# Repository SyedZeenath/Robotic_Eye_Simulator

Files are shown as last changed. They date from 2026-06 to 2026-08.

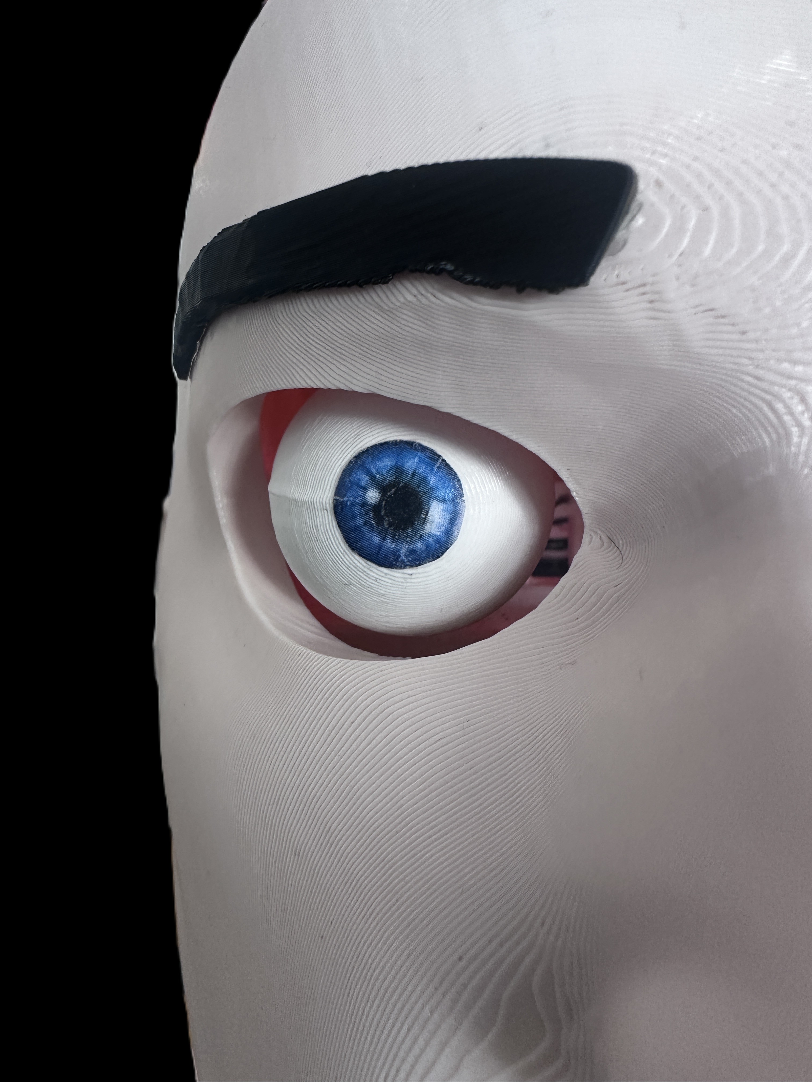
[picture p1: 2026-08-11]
Images/Evaluations/Eye_angles/h4.JPG

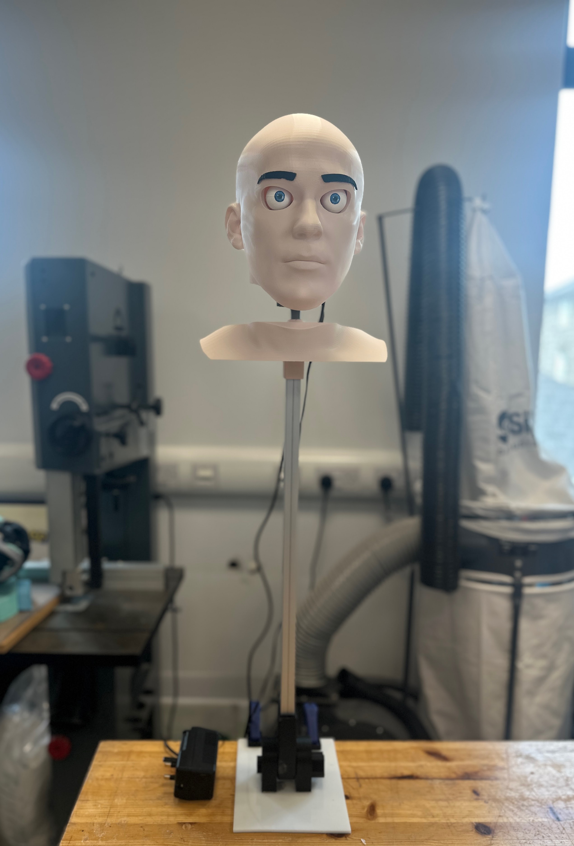
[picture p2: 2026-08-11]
Images/full_setup.JPG

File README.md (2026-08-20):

# Robotic Eye Movement Simulator for the Dix-Hallpike Test

## Overview

This dissertation project implements a robotic eye movement system for simulating the eye responses associated with the Dix-Hallpike test for BPPV research and training. The system combines Arduino-based hardware control, IMU head tracking, servo-driven eye movement and a Unity-based digital interface.

The platform provides real-time eye movement simulation, a guided clinical test workflow, patient data management, calibration tools and performance evaluation. The physical robotic head and the Unity model communicate through a USB serial connection.

## System Architecture

The system is divided into four main parts:

1. **Physical robotic platform** - A head and eye mechanism driven by six servo motors.
2. **Arduino controller** - Reads head movement from the MPU6050, controls the eye motors through the PCA9685 and communicates with Unity.
3. **Unity frontend** - Displays the digital head and eye model, manages the test workflow and provides monitoring and patient-management functions.
4. **Evaluation tools and data** - Calibration tools and recorded CSV data are used to evaluate positional synchronisation, latency and IMU behaviour.

### Data Flow

```text
Physical head movement / IMU
            ↓
        Arduino
            ↓
     USB Serial 115200
            ↓
 ArduinoSerialReader
            ↓
 RealisticEyeController
            ↓
  Unity head and eye model
            ↓
        User display
```

The Unity interface can also send commands back to the Arduino to start right-side, left-side or neutral sequences.

## Project Structure

### `/EyeController/`

Arduino firmware for motor control, IMU tracking, BPPV sequence control, calibration and evaluation.

- **`EyeController.ino`** - Main Arduino sketch containing:
  - MPU6050 head tracking using the Digital Motion Processor (DMP)
  - PCA9685 servo control
  - Six-channel eye movement control
  - Mirror-effect handling between the two eyes
  - Clinical test state machine
  - Physical-to-digital calibration lookup tables
  - Serial communication with Unity
  - Evaluation routines for positional synchronisation and IMU jitter/noise
  - `SKIP_IMU_TEST` option for bench testing without the IMU

### `/Frontend/`

Unity project containing the digital twin, user interface, clinical workflow and evaluation tools.

#### `Assets/Scripts/`

- **`ArduinoSerialReader.cs`** - Reads and parses serial data from the Arduino.
- **`RealisticEyeController.cs`** - Applies eye angles to the digital model and handles VOR compensation and head velocity tracking.
- **`SimulationUI.cs`** - Controls the main simulation interface.
- **`InstructionManager.cs`** - Controls the eight-step Dix-Hallpike instruction sequence.
- **`InstructionStep.cs`** - Defines an individual instruction step.
- **`DiagnosisFeedbackController.cs`** - Handles assessment feedback shown during the test.
- **`LatencyMonitor.cs`** - Records communication and timing information.
- **`SyncDebugOverlay.cs`** - Displays synchronisation and debugging information.
- **`EnvLoader.cs`** - Loads runtime environment and configuration settings from the `env` file in `Assets/StreamingAssets/` (see API Configuration below).
- **`RecordingIndicator.cs`** - Displays recording status.
- **`TTS_Script.cs`** / **`STT_Script.cs`** - Text-to-speech and speech-to-text functions.
- **`MicrophoneRecorder.cs`** - Handles audio recording.
- **`WavUtility.cs`** - Provides WAV file handling utilities.

#### `Assets/Scripts/PatientModel/`

- **`PatientManager.cs`** - Maintains the current patient data.
- **`Patient.cs`** - Defines the patient data model.
- **`PatientList.cs`** - Manages the patient collection.
- **`PatientItemUI.cs`** - Displays an individual patient entry.
- **`PatientListUI.cs`** - Controls the patient list interface.

#### Other Unity folders

- **`Assets/Scenes/`**
  - `MainScene.unity` - Main simulation scene.
  - `SampleScene.unity` - Development and testing scene.
- **`Assets/Prefab/`** - Reusable head and eye components.
- **`Assets/Resources/`** - Patient JSON data, textures, materials and other runtime resources.
  - `patients.json` - Patient data used by the application.
- **`Assets/StreamingAssets/`** - Additional runtime data and configuration, including the `env` configuration file (see API Configuration below). This folder is copied automatically into every build output, which is what lets the `env` file travel with a shared build without any manual copy step.
- **`Assets/Eye/`** - Eye model assets, materials and prefabs.
- **`Assets/HeadModel/`** - Head model assets and geometry.
- **`Packages/`** - Unity package configuration and dependencies.
- **`ProjectSettings/`** - Unity project and build settings.

Generated folders such as `Logs/` and `Temp/` are not required for the source project and can be omitted from version control.

### `/Models/`

CAD models for the physical robotic platform:

- **`Body_Of_Robotic_Bppv_Head.stl`** - Main head structure.
- **`Rod_Holder_Torso.stl`** - Torso mounting component.
- **`Eye_Mechanism/`** - Eye mechanism components.
- **`Head/`** - Head assembly components.
- **`Neck/`** - Neck joint components.
- **`Base_Hinge_Joint/`** - Base hinge components.

### `/Helpers/`

- **`photo_angle_measurer.html`** - Browser-based tool used to measure physical eye angles during calibration.

### `/Images/`

Evaluation and calibration material:

- **`Evaluations/Eye_angles/`** - Recorded eye-angle measurements.
- **`Evaluations/Head_angles/`** - Recorded head-angle measurements.
- Calibration screenshots and supporting images.

### `/Builds/`

Prebuilt standalone application and evaluation data generated during testing:

- **A prebuilt `.exe` and its accompanying `_Data` folder** - the standalone Windows build of the application. If no changes need to be made to the project, this can be run directly without opening or importing the project in Unity. Run the `Robotic_Eye_Simulator.exe` from inside this folder as-is; the `_Data` folder (which contains the bundled `StreamingAssets/env` file among other runtime data) must stay alongside the `Robotic_Eye_Simulator.exe`, since a Unity build is not a single portable file. Copying or sharing the `Robotic_Eye_Simulator.exe` on its own, without its `_Data` folder, will not run.
  (Only for the dissertation scope; `/Builds/` may be removed later.)
- **`latency_results.csv`** - Serial communication latency measurements.
- **`sync_results.csv`** - Motor synchronisation measurements.
- **`transfer_latency_results.csv`** - Data transfer latency measurements.

## Hardware Requirements

The tested system uses:

- **Arduino UNO R3** - Main microcontroller.
- **MPU6050** - Six-axis accelerometer/gyroscope for head tracking.
- **PCA9685** - 16-channel PWM driver for servo control.
- **Six servo motors**:
  - Right eye: horizontal, vertical and torsional movement.
  - Left eye: horizontal, vertical and torsional movement.
- **Motor power supply** - Separate suitable supply for the servo motors.
- **USB connection** - Arduino-to-PC serial communication.

### PCA9685 Channel Mapping

| Eye | Horizontal | Vertical | Torsion |
| ----- | ---: | ---: | ---: |
| Right | CH0 | CH1 | CH2 |
| Left  | CH4 | CH5 | CH6 |

Channels CH3 and CH7-15 are unused by the current implementation.

## Software Requirements

- **Arduino IDE** 1.8.x or later.
- **I2Cdev** library.
- **MPU6050** library with DMP support.
- **Adafruit PWM Servo Driver** library.
- **Unity** 2022.x or later; an LTS release is recommended.
- **TextMesh Pro** for the Unity interface.
- **Windows audio system** for the TTS/STT functions.
- **Visual Studio** for C# development.

## Setup

### 1. API Configuration

The Unity application uses Google Cloud Text-to-Speech (TTS) and Speech-to-Text (STT) services. The required API keys must be stored in a plain-text configuration file named **`env`** (no leading dot) placed at:

```text
Assets/StreamingAssets/env
```

The leading dot was dropped deliberately: Unity's asset importer does not reliably include files whose names begin with a dot when copying `StreamingAssets` into a build, so a dotfile placed there can silently fail to ship with the built application. Naming the file `env` instead avoids this and ensures it is bundled correctly every time the project is built.

Create the file by copying the format from `Frontend/.env.example`:

```env
GOOGLE_TTS_API_KEY=your-google-cloud-tts-api-key-here
GOOGLE_STT_API_KEY=your-google-cloud-stt-api-key-here
```

For the dissertation version, the personal API keys required to run the application are already included in the `Frontend/.env.example` file for demonstration and evaluation purposes. These keys will be removed after the dissertation evaluation. These keys can be used now for testing the application.

To create new API keys, create or select a project in the Google Cloud Console, enable the **Cloud Text-to-Speech API** and **Cloud Speech-to-Text API**, then create an API key under **APIs & Services → Credentials**. Add the generated keys to the corresponding entries in `env`.

`EnvLoader.cs` reads this file via `Application.streamingAssetsPath`, which resolves correctly both in the Unity Editor and in a standalone build, so no manual copying is required as long as the file lives in `Assets/StreamingAssets/env` before building.

The `env` file should not be committed to version control.

### 2. Arduino

1. Install the Arduino IDE.
2. Install the required I2Cdev, MPU6050 and Adafruit PWM Servo Driver libraries.
3. Connect the MPU6050 and PCA9685 to the Arduino I2C interface.
4. Connect the six servo motors to the PCA9685 channels listed above.
5. Open `EyeController/EyeController.ino`.
6. Select the correct board and COM port.
7. Upload the firmware.

For bench testing without the IMU, set:

```cpp
SKIP_IMU_TEST = true
```

The serial interface uses **115200 baud**.

### 3. Unity

1. Install Unity 2022.x or a compatible LTS release.
2. Open the `Frontend/` directory through Unity Hub.
3. Allow Unity to complete the initial asset import.
4. Open `Assets/Scenes/MainScene.unity`.
5. Check the `ArduinoSerialReader` component and confirm the COM port.
6. Confirm the baud rate is set to 115200.
7. Check the patient data file if patient information needs to be changed.
8. Press **Play** to test the application in the Unity Editor.

TTS/STT functions require the appropriate Windows audio and microphone permissions.

> **Note:** If you only need to run the application as-is, with no code, scene, or asset changes, you do not need to open Unity at all. See `/Builds/` above for the prebuilt `.exe`.

## Calibration

The physical eye mechanism requires calibration before comparing physical and digital eye positions.

### Photo Angle Measurement

Open:

```text
Helpers/photo_angle_measurer.html
```

The tool is used to measure physical eye angles and relate them to the corresponding digital motor commands. The resulting values are used by the calibration lookup tables in the Arduino firmware.

### Evaluation Data Collection

The firmware contains a separate evaluation section for:

- Positional synchronisation testing.
- IMU jitter and noise measurements.
- Calibration data collection.

The Unity application also provides `LatencyMonitor` and `SyncDebugOverlay` components for monitoring system behaviour during testing.

Evaluation results are stored in the `/Builds/` directory.

## Communication Protocol

Communication between Arduino and Unity uses text-based USB serial communication at 115200 baud.

### Unity → Arduino

```text
R                  Right-side BPPV sequence
L                  Left-side BPPV sequence
N                  Neutral position
C:<h>,<v>,<t>      Calibration command
```

### Arduino → Unity

The Arduino sends status and eye-angle information in a text format containing the current phase and horizontal, vertical and torsional angles.

The exact message format is implemented in `EyeController.ino` and parsed by `ArduinoSerialReader.cs`.

## Running the System

### Quick Run (no changes needed)

If the application does not need any modification, the prebuilt standalone build in `/Builds/` can be run directly. The application opens at the home section, which is the starting point for patient selection, simulation and evaluation:

1. Open the `/Builds/` folder.
2. Run the `Robotic_Eye_Simulator.exe` found there directly, no Unity installation required on the target machine.
3. Keep the `Robotic_Eye_Simulator.exe` and its accompanying `_Data` folder together in the same location; do not copy or share the `Robotic_Eye_Simulator.exe` on its own.
4. Connect the Arduino and confirm the correct COM port as described in the Troubleshooting section if the serial connection is not detected automatically.

### Bench Test

For motor-only testing:

1. Set `SKIP_IMU_TEST = true`.
2. Upload the Arduino firmware.
3. Open the Serial Monitor at 115200 baud.
4. Send `R`, `L` or `N`.
5. Check that the motors respond correctly.

### Full System Test

1. Connect the Arduino and physical eye mechanism.
2. Connect the MPU6050.
3. Start the Unity application (either the Editor or the prebuilt `Robotic_Eye_Simulator.exe`).
4. Confirm that the serial connection is active.
5. Select a patient if required.
6. Start the Dix-Hallpike test workflow.
7. Follow the on-screen instructions.
8. Monitor the physical and digital eye movements.
9. Use the debugging and latency tools when collecting evaluation data.

### Clinical Test Workflow

The Unity interface provides an eight-step test sequence covering the right and left sides. The instruction system guides the user through the sequence, while the digital head and eye model display the corresponding movement.

Patient information and test outcomes can be stored through the patient-management system.

## Evaluation and Monitoring

The project includes tools for evaluating the physical and digital system.

### Latency

`LatencyMonitor.cs` records communication timing during system operation. Recorded latency results are stored as CSV data for later analysis.

### Positional Synchronisation

The physical eye positions are compared with their corresponding digital positions using calibration and synchronisation data.

### IMU Stability

The Arduino evaluation section can be used to collect IMU jitter and noise data while the head is held in controlled positions.

### Debugging

`SyncDebugOverlay.cs` can display:

- Current test phase.
- Motor angles.
- Head rotation.
- IMU information.
- Timing information.

These tools are intended for development and evaluation and can be disabled during normal operation.

## Key Features

### Robotic Eye and Head System

- Independent three-axis movement for each eye.
- Six servo-driven eye axes.
- MPU6050-based head tracking.
- PCA9685 PWM motor control.
- Calibration lookup tables for physical-to-digital angle mapping.
- Mirror-effect handling between the two eyes.

### Unity Digital Twin

- Real-time 3D head and eye visualisation.
- Serial-driven eye movement.
- Head rotation visualisation.
- VOR compensation.
- Guided Dix-Hallpike workflow.

### Patient and Test Management

- JSON-based patient data.
- Patient selection and management.
- Test result and diagnosis feedback.
- Eight-step test instruction system.
- TTS/STT functions.
- Microphone recording support.

### Evaluation

- Serial latency monitoring.
- Positional synchronisation testing.
- IMU jitter/noise testing.
- Calibration tools.
- CSV export of evaluation data.

## Technical Details

### Arduino Firmware

The firmware is organised into the following sections:

1. **Declarations** - Configuration values, calibration data, state variables and IMU data.
2. **BPPV Core** - Motor control, calibration, state-machine operation, head tracking and serial commands.
3. **Evaluation** - Positional synchronisation and IMU data collection.
4. **Main Loop** - Continuous IMU processing, motor updates, serial handling and telemetry.

The BPPV sequence is implemented as a state machine covering the required test phases.

### Eye Motor Control

The PCA9685 controls six servo channels. Physical motor positions are mapped to target angles using calibration data. Smoothing is applied to reduce visible movement caused by variations in serial updates.

The left and right eye movements use mirrored horizontal and torsional values where required by the mechanical arrangement.

### IMU and Head Tracking

The MPU6050 provides accelerometer and gyroscope measurements. Its Digital Motion Processor is used for quaternion-based motion processing. Head pitch, roll and yaw are used by the Unity system for head movement and VOR-related calculations.

### Data Persistence

- **Patient data:** JSON format in `Assets/Resources/patients.json`.
- **Configuration/secrets:** `env` file in `Assets/StreamingAssets/`.
- **Evaluation results:** CSV files in `Frontend/`.
- **Calibration:** Stored in the Arduino firmware calibration data.

## Building the Unity Application

1. Open **File → Build Settings**.
2. Add `Assets/Scenes/MainScene.unity`.
3. Select Windows as the target platform used for this project.
4. Configure the required resolution and presentation settings.
5. Build the standalone application.
6. Confirm that `Assets/StreamingAssets/env` exists before building, so the required API keys are bundled into the output automatically.
7. On the target system, connect the Arduino and confirm the serial port configuration.

The application was developed and tested on Windows 10/11.

> **Sharing a build:** always share the full build output folder (the `Robotic_Eye_Simulator.exe` together with its `_Data` folder), never the `Robotic_Eye_Simulator.exe` file alone. The `_Data` folder contains `StreamingAssets/env` and other runtime data the application needs to run.

## Troubleshooting

### Serial connection is not detected

- Check that the Arduino is connected.
- Confirm the COM port in `ArduinoSerialReader`.
- Confirm that both sides use 115200 baud.
- Close other applications using the same serial port.
- Restart the Arduino and Unity application if necessary.

### Motors do not move

- Check the PCA9685 I2C connection.
- Check the PCA9685 address.
- Check the separate motor power supply.
- Check the servo connections.
- Test the `R`, `L` and `N` commands through the Serial Monitor.

### IMU does not initialise

- Check the MPU6050 SDA/SCL connections.
- Confirm that the required MPU6050 and I2Cdev libraries are installed.
- Check the I2C address.
- Use `SKIP_IMU_TEST = true` for motor-only testing.

### Eye movement is unstable

- Check the motor power supply.
- Check USB and I2C connections.
- Check the smoothing setting in `RealisticEyeController`.
- Use the synchronisation overlay to identify whether the problem originates from the physical or digital side.

### TTS/STT does not work

- Confirm the `env` file exists at `Assets/StreamingAssets/env` (or, for a built application, inside the `_Data/StreamingAssets/` folder shipped alongside the `.exe`) and that the Google Cloud TTS and STT API keys are correctly set inside it, as described in the API Configuration section.
- If running a shared build, confirm the `Robotic_Eye_Simulator.exe` was not copied or shared without its `_Data` folder.
- Check Windows microphone permissions.
- Confirm that the correct audio input/output devices are selected.
- Check Unity audio settings.
- If nothing appears on screen, check `Player.log` (typically under `%USERPROFILE%\AppData\LocalLow\<CompanyName>\<ProductName>\Player.log` on Windows) for the specific error, since a standalone build has no visible console by default.

## Testing Strategy

The project uses several levels of testing:

- **Component testing** - Individual motor, IMU and serial functions.
- **Integration testing** - Arduino-to-Unity communication and digital eye response.
- **System testing** - End-to-end operation of the physical and digital systems.
- **Evaluation testing** - Latency, positional synchronisation and IMU stability measurements.

The detailed experimental methodology and results are documented in the dissertation.

## Development and Extension

The main extension points are:

1. **Additional BPPV sequences** - Extend the Arduino state machine.
2. **Additional patient fields** - Update `Patient.cs` and the JSON data structure.
3. **Additional instructions** - Extend the instruction definitions in `InstructionManager`.
4. **Motor calibration** - Update the calibration data for the relevant PCA9685 channels.

## Limitations and Notes

- The system was developed and tested primarily on Windows 10/11.
- The physical platform and digital model require calibration before positional comparisons are made.
- Servo response and mechanical accuracy depend on the physical hardware and power supply.
- TTS/STT functionality depends on the host computer's audio configuration.
- The system is intended as a research and training platform; clinical diagnostic validity has not been established by this project.
- Hardware limits should be maintained to prevent the eye mechanism from being driven beyond its safe mechanical range.
- Sharing the application requires sharing the full build output folder; the `Robotic_Eye_Simulator.exe` alone will not run and will not carry the bundled `env` configuration.

## Future Work

Possible extensions include:

- Supporting additional BPPV canal variants.
- Increasing the available torsional mechanical range.
- Evaluating trainee learning outcomes.
- Developing an alternative interface for training and demonstration.

## Project Status

- **Project:** Dissertation research project.
- **Platform:** Arduino + Unity.
- **Primary target:** Windows 10/11.
- **Physical system:** Robotic head with six servo-driven eye axes.
- **Main application:** BPPV/Dix-Hallpike simulation and research evaluation.

## Acknowledgments

I thank Dr. JahanZeb Gul and Dr. Gerard Boyle for their supervision and feedback throughout this project. I'm also grateful to the clinical nursing staff and the design engineering team at St.James's Hospital, Dublin, whose consultation shaped the assessment protocol and instruction language used in this platform.

Particular thanks go to Arslan Akhtar, a Year 3 Innovation & Design student at Maynooth University, who worked as part of the St.James's design team during his internship there and contributed to the mechanical design of the head and support structures.

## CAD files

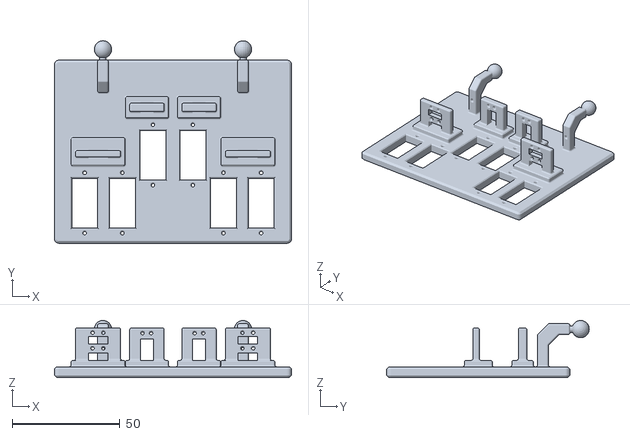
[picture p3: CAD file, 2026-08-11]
Models/Eye_Mechanism/Full_base.STL
110.0 x 94.0 x 26.5

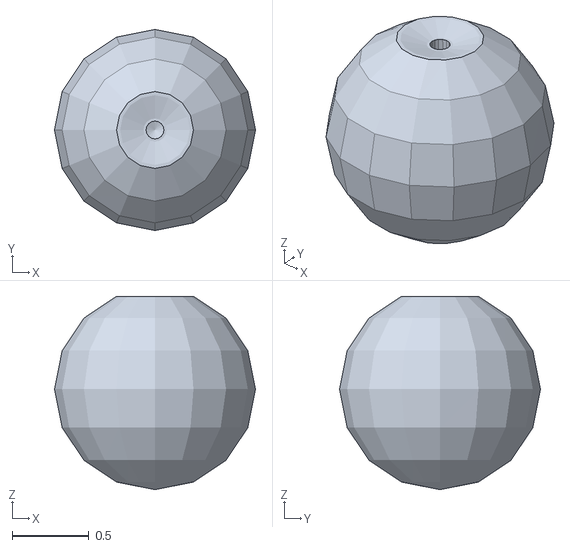
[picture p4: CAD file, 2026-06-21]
Frontend/Assets/Eye/Model/iris.obj
1.31 x 1.31 x 1.26

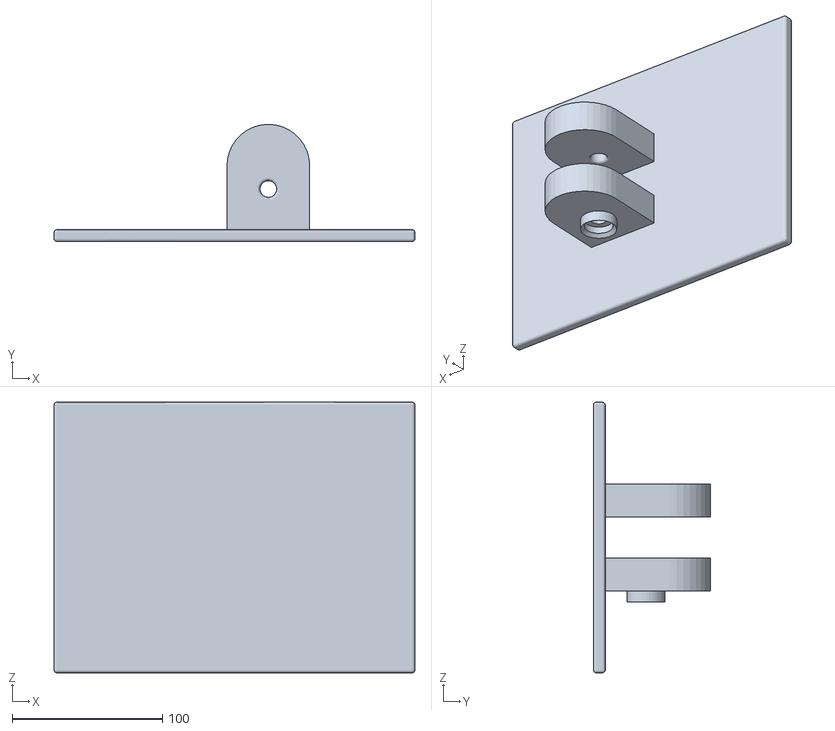
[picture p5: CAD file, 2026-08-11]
Models/Base_Hinge_Joint/base.STL
240.0 x 78.0 x 180.0

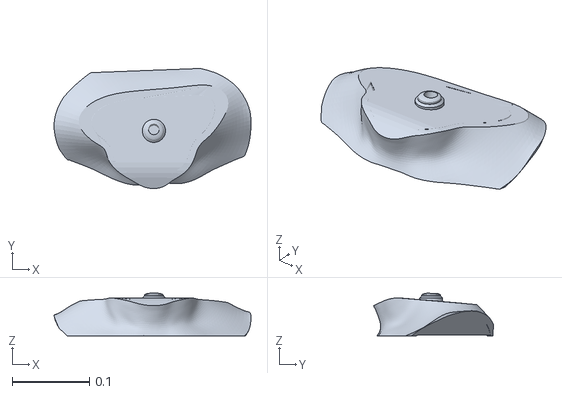
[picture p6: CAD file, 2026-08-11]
Models/Body Of Robotic Bppv Head.stl
0.256 x 0.156 x 0.0555

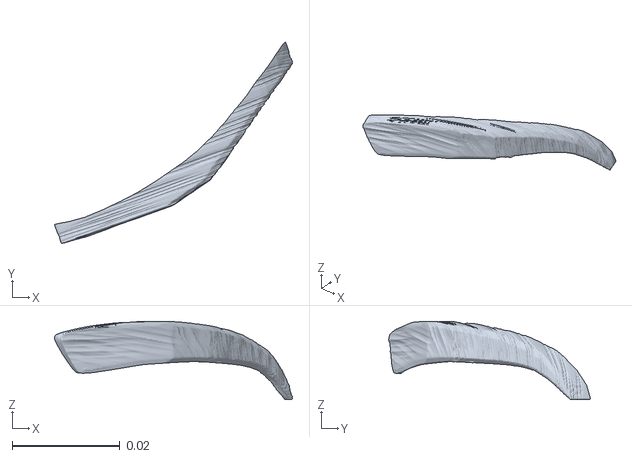
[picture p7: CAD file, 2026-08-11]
Models/Head/EyeBrow Left.stl
0.0441 x 0.0374 x 0.0145

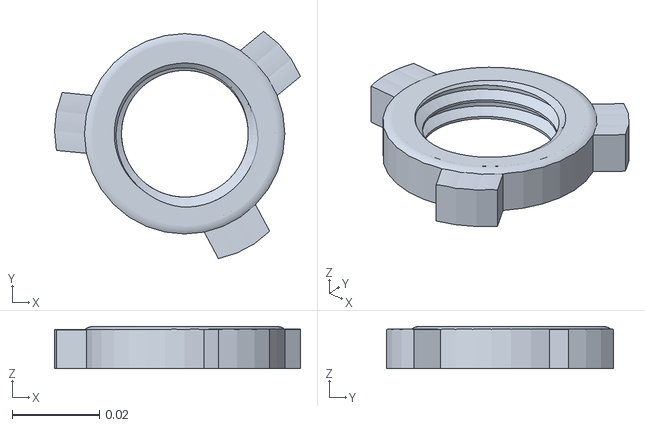
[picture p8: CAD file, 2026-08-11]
Models/Neck/Tightner Ball Joint .stl
0.0565 x 0.0522 x 0.00976

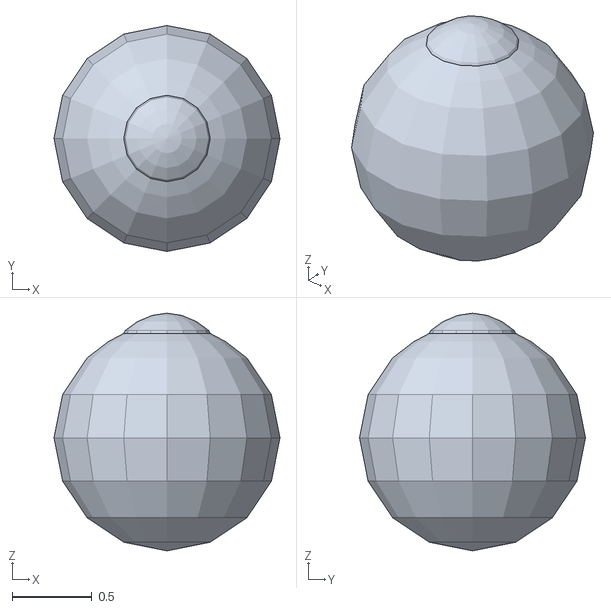
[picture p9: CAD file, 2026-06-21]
Frontend/Assets/Eye/Model/sclera.obj
1.42 x 1.42 x 1.49

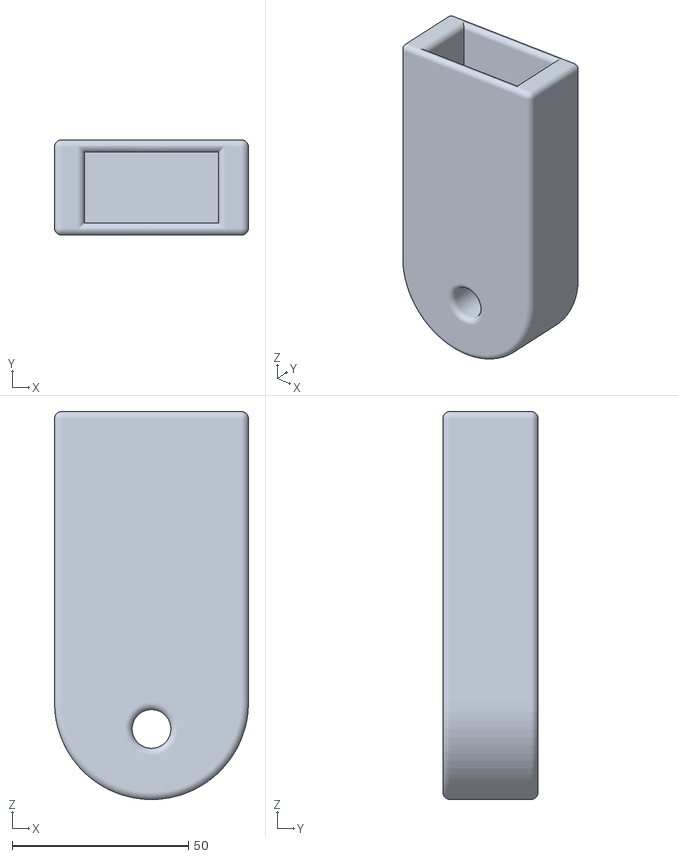
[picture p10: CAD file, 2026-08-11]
Models/Base_Hinge_Joint/RodAttachment.STL
55.0 x 27.0 x 110.0

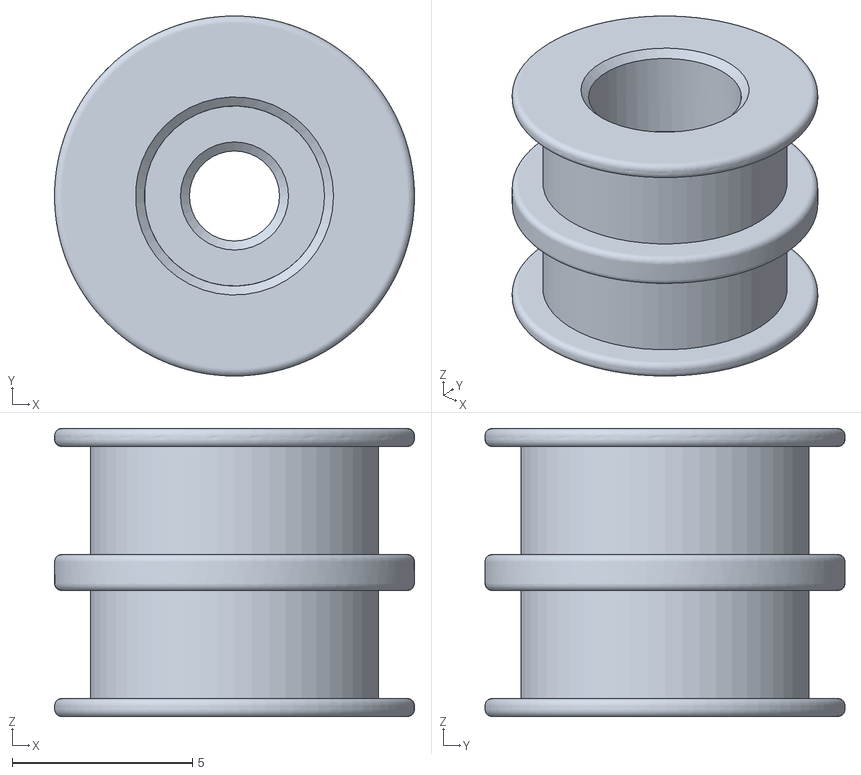
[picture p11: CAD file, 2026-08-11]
Models/Eye_Mechanism/motor_dual_spool.STL
10.0 x 10.00 x 8.00

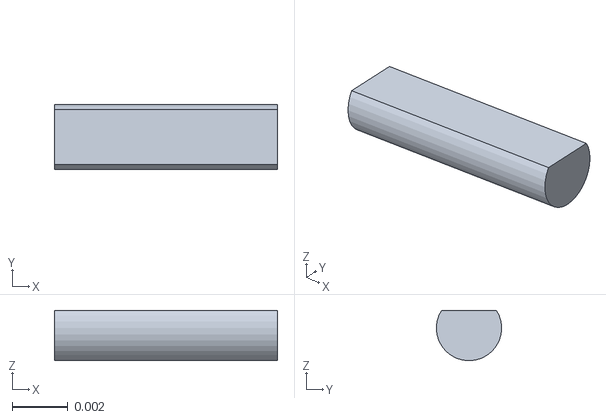
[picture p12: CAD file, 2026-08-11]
Models/Head/POwer Controller Pins.stl
0.008 x 0.00235 x 0.00181

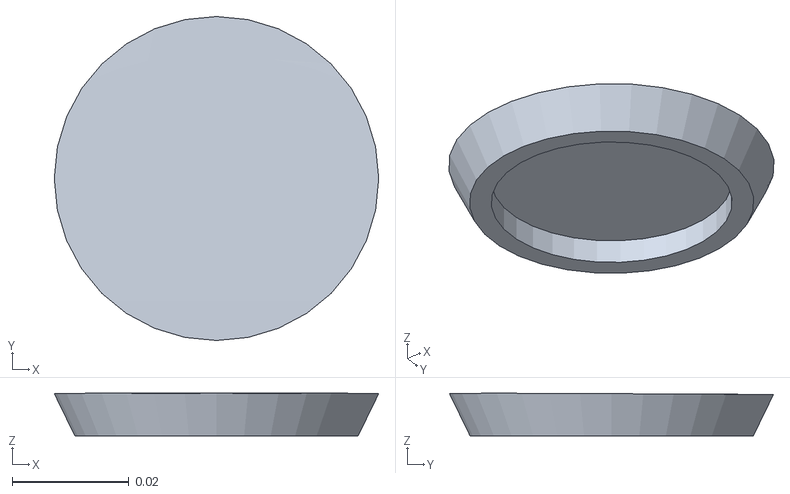
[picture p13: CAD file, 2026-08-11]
Models/Neck/Head Joint Holder .stl
0.0556 x 0.0555 x 0.00732

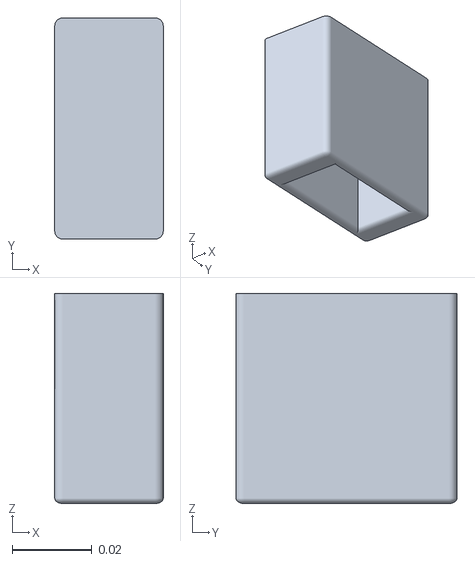
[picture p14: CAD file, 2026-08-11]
Models/Rod Holder Torso.stl
0.0273 x 0.0556 x 0.0528

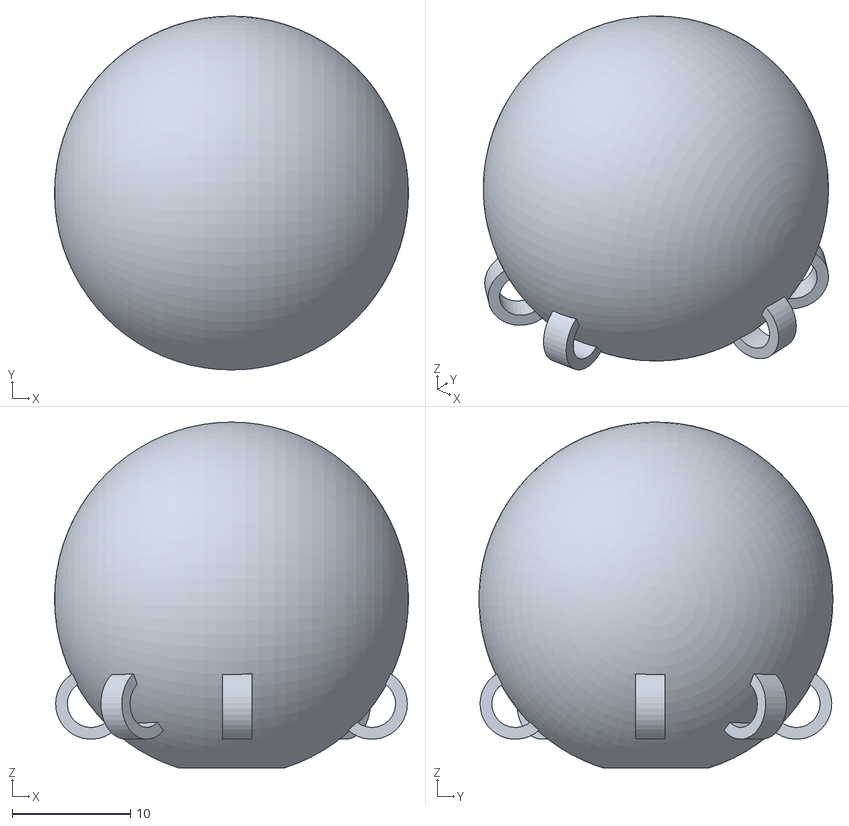
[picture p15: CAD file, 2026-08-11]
Models/Eye_Mechanism/Eye_Sphere_loop.STL
30.0 x 30.0 x 29.3

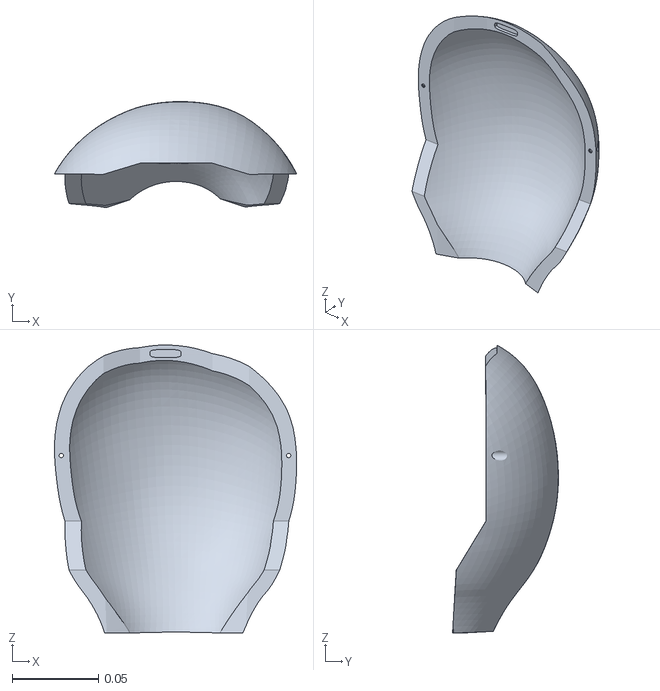
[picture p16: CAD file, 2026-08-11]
Models/Head/Backdoor.stl
0.14 x 0.0613 x 0.167

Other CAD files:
Models/Head/Power Controller Holder Side wall .stl
Models/Neck/Ball Joint.stl
Models/Head/Head .stl
Models/Base_Hinge_Joint/Screw_Head.STL
Models/Neck/Screw Ball Joint.stl

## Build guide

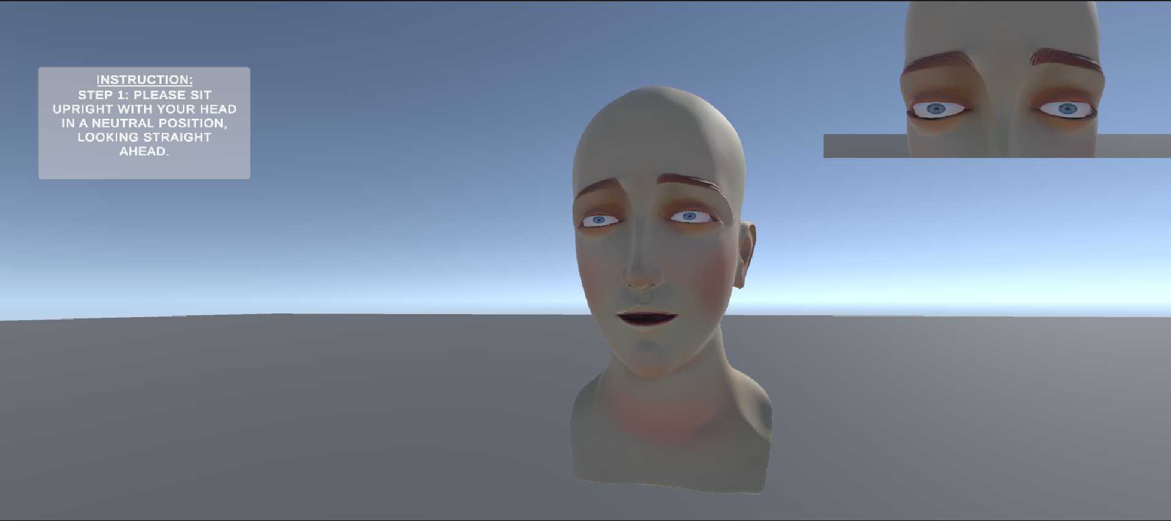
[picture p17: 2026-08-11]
Images/step2-Unity.png

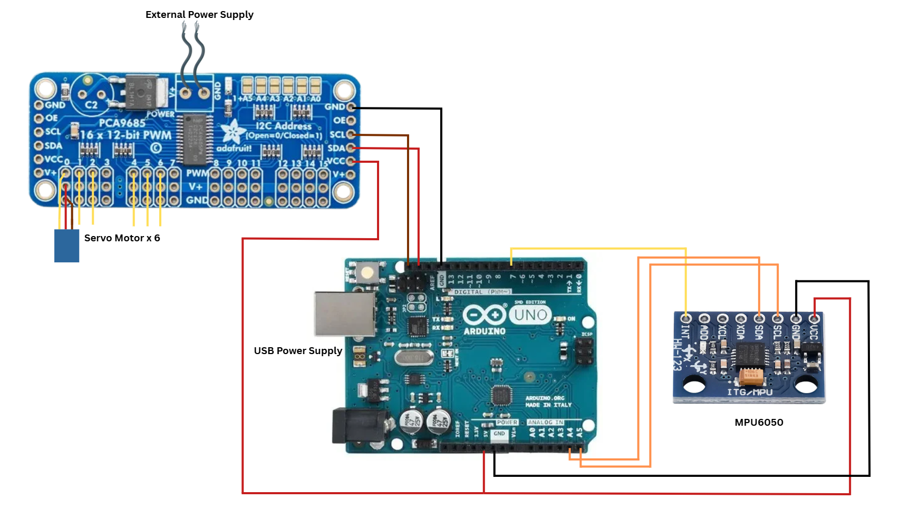
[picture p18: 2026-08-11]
Images/wiringDiagram.png

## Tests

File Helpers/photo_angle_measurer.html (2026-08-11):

# Photo Angle Measurer

The zoom helps you see the pixel, but a mouse click is still limited to the screen's resolution, not the photo's, so it can't reliably land on the exact same image pixel twice. To actually get pixel-repeatable points: every canvas below now shows the live cursor position in real image pixels, click a point roughly where you want it, then use the arrow keys to nudge the last point 1px at a time (hold Shift for 5px) while watching the X/Y readout, or just type the exact X,Y pixel values into the boxes and hit "Add point at typed pixel" to place it with no mouse imprecision at all. Note down the X/Y numbers for a point you like, and you can type those exact same numbers back in next time.

## Mode 1: Torsion (in-plane rotation angle)

Use this for torsion only. Click three points in order:

1. Pivot (red) - center of the pupil/iris (torsion rotates around this point, it does not move)
2. Fixed reference (blue) - an identifiable mark on the STATIC housing (paint dot, screw, seam) that does NOT move with the eye. Defines your 0deg direction.
3. Moving marker (green) - a specific identifiable spot in the iris texture pattern, placed near the EDGE of the iris, well away from the pivot. The farther from the pivot, the more precise the reading.

zoom

cursor: (-, -) X: Y: Add point at typed pixel Arrow keys nudge the last placed point (Shift = 5px).

Load a photo, then click: 1) pivot, 2) fixed reference, 3) moving marker.

No neutral set yet. Measure your 0deg commanded photo first, then click "Set as neutral".

Set as neutral (this = 0deg) Record this measurement Reset points (same photo) Download recorded CSV

# | label | raw angle (deg) | torsion vs neutral (deg)

## Mode 2: Vertical / Horizontal (displacement angle)

Vertical and horizontal eye movement is NOT an in-plane rotation as seen from a straight-on camera - it shows up as the pupil sliding up/down or left/right in the frame. This mode measures that displacement and converts it to degrees using the eye's own radius, so it needs a fixed camera position (tripod) between the neutral shot and every test shot - if the camera moves, the numbers are meaningless.

### Step A: set the neutral position (eye at 0,0,0)

Load the neutral photo. First click 3 to 8 points spread around the IRIS edge (the blue/dark ring, not the white sclera edge) — more points, spread further around the visible arc, gives a better fit. Click "Finish iris" when done, it'll fit a circle through your points and show it. Then do the same for the PUPIL edge (the black circle in the middle) and click "Finish pupil".

zoom

cursor: (-, -) X: Y: Add point at typed pixel Adds to whichever set (iris/pupil) you're currently on. Arrow keys nudge the last point (Shift = 5px).

Load the neutral photo, then click points around the iris edge.

Undo last point Finish iris points Finish pupil points Reset (same photo)

### Step B: measure each test photo

Load a test photo (same camera position as neutral). Click 3 to 8 points around the PUPIL edge, then click "Finish points" to fit and compute.

zoom

cursor: (-, -) X: Y: Add point at typed pixel Arrow keys nudge the last point (Shift = 5px).

Set the neutral position above first.

Undo last point Finish points

Record this measurement Download recorded CSV

# | label | vertical (deg) | horizontal (deg)

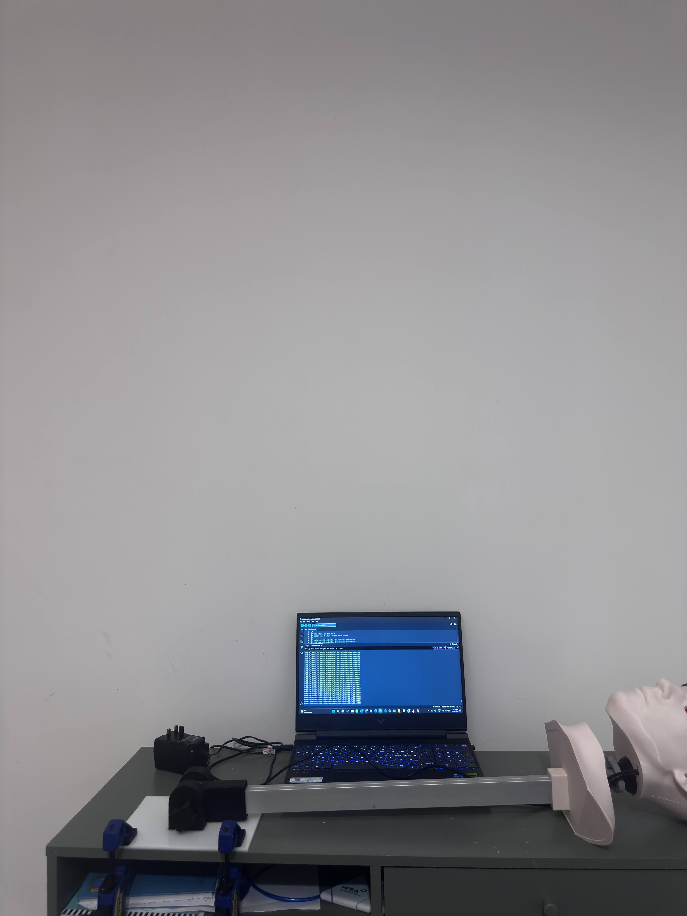
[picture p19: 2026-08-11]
Images/Evaluations/Head_angles/pitch_85.JPG

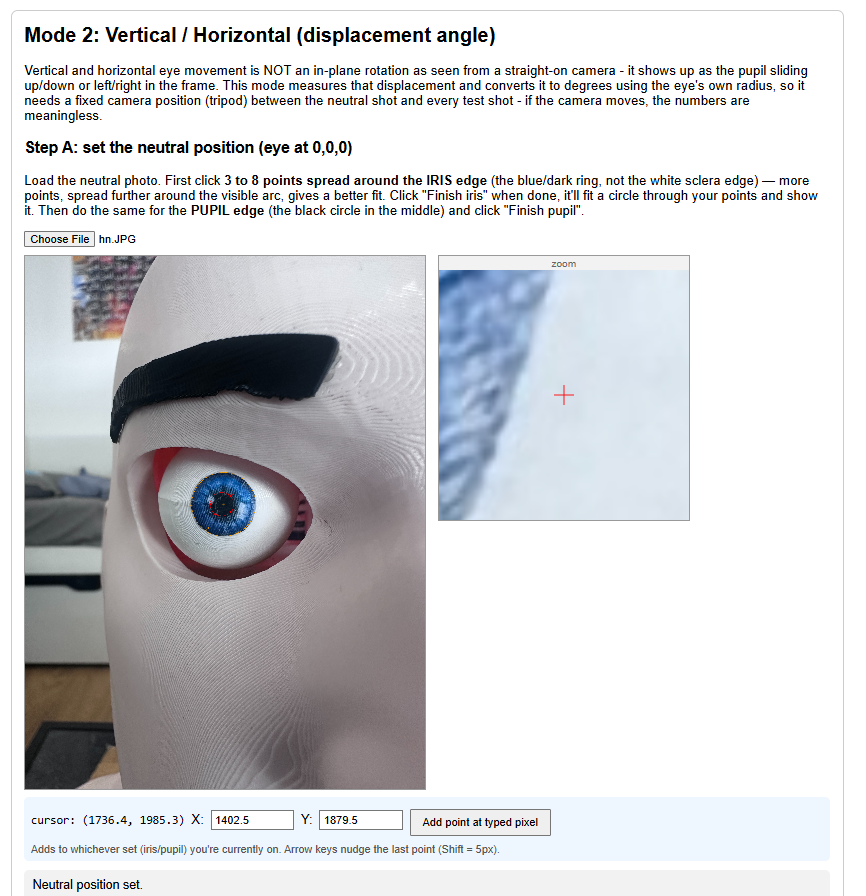
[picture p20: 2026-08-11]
Images/Evaluations/ToolScreenshot02.png

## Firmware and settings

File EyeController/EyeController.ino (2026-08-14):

/*
 * BPPV Robotic Eye Simulation
 * MPU6050 Head Tracker + PCA9685 Motor Driver
 *
 * Right eye: CH0=horizontal, CH1=vertical, CH2=torsion
 * Left eye:  CH4=horizontal, CH5=vertical, CH6=torsion
 *
 * Both eyes move with mirror effect - horizontal and torsion signs flip
 * N or NEUTRAL -> all motors neutral
 *
 * File layout:
 *   1. Declarations (structs, config constants, global state) - unchanged
 *      order throughout, since Arduino auto-generates function prototypes
 *      and inserts them immediately before the first function in the file;
 *      any struct used in a function signature must therefore stay up here,
 *      above every function, or the sketch fails to compile.
 *   2. SECTION 1 - BPPV CORE: everything needed to actually run a clinical
 *      exam (motor control, calibration, state machine, head tracking,
 *      core serial commands).
 *   3. SECTION 2 - DATA COLLECTION FOR EVALUATION: code that exists purely
 *      to gather the data behind the dissertation's evaluation section
 *      (positional-sync calibration test mode, IMU jitter/noise trial).
 *      None of this runs during a normal triggered exam.
 *   4. setup() / loop()
 */

#include <Wire.h>
#include <I2Cdev.h>
#include <MPU6050_6Axis_MotionApps20.h>
#include <Adafruit_PWMServoDriver.h>
#include <string.h>
#include <stdlib.h>

// Calibration lookup-table entry (physical eye angle -> digital command
// that actually achieves it). Declared here, immediately after the
// includes and before any function, because compensate() takes a
// CalPoint* parameter and Arduino's auto-generated prototype for it must
// be able to see this type.
struct CalPoint { float physical; float digital; };

// **********************************************
// DEV/DEBUG TOGGLE
// Lets the sketch run and auto-trigger a BPPV sequence without a
// connected IMU, for bench testing the motors alone.
// **********************************************
#define SKIP_IMU_TEST   false
#define BPPV_SIDE       'R'

// **********************************************
// IMU (MPU6050 + DMP)
// **********************************************
MPU6050 mpu;
bool dmpReady = false;
uint8_t devStatus;
uint16_t packetSize;
uint8_t fifoBuffer[64];
Quaternion q;
VectorFloat gravity;
float yawOffset = 0, pitchOffset = 0, rollOffset = 0;
const unsigned long stabilizationDelay = 15000;
const int calibrationSamples = 100;
float imuYaw = 0, imuPitch = 0, imuRoll = 0;   // Kalman-filtered, broadcast to Unity
float tiltFromVertical = 0;

struct EulerAngles {
    float pitch;
    float roll;
    float yaw;
    float tilt;
};

// **********************************************
// PCA9685 / servo output
// **********************************************
Adafruit_PWMServoDriver pca = Adafruit_PWMServoDriver(0x40);

#define PWM_FREQ      50
#define PULSE_MIN     205
#define PULSE_MAX     410
#define PULSE_NEUTRAL 307

#define R_CH_HORIZONTAL  0
#define R_CH_VERTICAL    1
#define R_CH_TORSION     2

#define L_CH_HORIZONTAL  4
#define L_CH_VERTICAL    5
#define L_CH_TORSION     6

#define SERVO_NEUTRAL 90
#define SERVO_MIN     12
#define SERVO_MAX     168

// Vertical uses one gain both directions (no asymmetry found for this
// axis). Torsion/horizontal use separate positive/negative gains, defined
// with the rest of the calibration machinery further down.
#define GAIN_VERTICAL   3.5

// **********************************************
// BPPV clinical parameters (exam timing + target angles)
// **********************************************
#define PEAK_TORSION_DEG     19.0
#define PEAK_VERTICAL_DEG    18.0
#define PEAK_HORIZONTAL_DEG  6.0

#define LATENCY_MS      3000
#define CRESCENDO_MS    4000
#define NYSTAGMUS_MS    10000
#define DECRESCENDO_MS  8000
#define REVERSAL_MS     6000

#define BEAT_DRIFT_DEG        14.0
#define BEAT_DRIFT_SPEED_TOR  22.0
#define BEAT_DRIFT_SPEED_VER  14.0
#define BEAT_DRIFT_SPEED_HOR   5.5
#define BEAT_SNAP_SPEED      120.0

#define LATENCY_DRIFT_DEG         1.5
#define CRESCENDO_TARGET_TORSION  16.0
#define CRESCENDO_TARGET_VERTICAL 14.0
#define TAU_DECAY                 12.0
#define LOOP_INTERVAL_MS          10

// **********************************************
// Motor / exam state
// **********************************************
float eyeTorsion    = 0.0;
float eyeVertical   = 0.0;
float eyeHorizontal = 0.0;

float headYaw   = 0;
float headPitch = 0;
float headRoll  = 0;

enum BeatState { BEAT_DRIFT, BEAT_SNAP };
BeatState beatState = BEAT_DRIFT;

// motorDir: +1 = right posterior BPPV, -1 = left posterior BPPV
int motorDir = 1;

// activeEye: 'R' = right eye channels active, 'L' = left eye channels active
char activeEye = 'R';

int  currentPhase  = 0;
bool motorRunning  = false;
unsigned long phaseStartTime = 0;
unsigned long lastMotorStep  = 0;

// True while loop() is holding eyeTorsion/eyeVertical/eyeHorizontal at a
// fixed value set by a "C:" command (see SECTION 2), instead of running
// the exam state machine. Declared here since both the core loop() and
// the Section 2 command handler need it.
bool testModeActive = false;

// Fixed-size serial receive buffer (no heap allocation / fragmentation
// risk from using String on a memory-constrained board). Shared by every
// serial command, core and data-collection alike.
#define SERIAL_BUF_SIZE 21
char serialBuffer[SERIAL_BUF_SIZE] = "";
uint8_t serialBufferLen = 0;

// Simple single-axis Kalman filter used to smooth the raw DMP output
// before it's broadcast to Unity. Operational (runs every loop), not
// evaluation-only.
struct Kalman1D {
    float process_noise = 0.001;   // process noise
    float measured_noise = 0.05;   // measurement noise
    float error_estimate = 1.0;    // estimate error covariance
    float current_estimate = 0.0;  // current estimate

    float update(float measured_value) {
        error_estimate += process_noise;  // prediction step: uncertainty grows each step
        float kalman_gain = error_estimate / (error_estimate + measured_noise); // trust measurement vs. prediction
        current_estimate += kalman_gain * (measured_value - current_estimate);  // update estimate
        error_estimate *= (1.0 - kalman_gain); // update error covariance
        return current_estimate;
    }
};

Kalman1D kalYaw, kalPitch, kalRoll;

// Running mean/variance accumulator (Welford's algorithm) used only by
// the IMU jitter trial in SECTION 2, to characterise head-tracking noise
// for the dissertation's evaluation section. Declared up here (not next
// to the functions that use it) because printStat() takes a RunningStats&
// parameter, which is subject to the same prototype-ordering constraint
// as CalPoint above.
struct RunningStats {
    long n = 0;
    float mean = 0.0f;
    float M2 = 0.0f;

    void update(float x) {
        n++;
        float delta = x - mean;
        mean += delta / n;
        float delta2 = x - mean;
        M2 += delta * delta2;
    }

    float variance() { return n > 1 ? M2 / (n - 1) : 0.0f; }
    float stddev()   { return sqrt(variance()); }
    void reset()     { n = 0; mean = 0.0f; M2 = 0.0f; }
};

RunningStats rawYawStats, filtYawStats;
RunningStats rawPitchStats, filtPitchStats;
RunningStats rawRollStats, filtRollStats;
RunningStats tiltStats; // no filtered counterpart, tiltFromVertical is unfiltered by design

bool jitterTrialActive = false;
const unsigned long JITTER_SAMPLES = 300; // ~3s at ~100Hz DMP output


// ================================================================
// SECTION 1 - BPPV CORE
// Everything needed to run a real triggered exam: calibration,
// motor control, the clinical state machine, head tracking, and the
// core serial command set (R/L/N/RESET).
// ================================================================

// --- Positional-sync calibration tables ---
// Built from photographic measurement of achieved vs. commanded eye
// angle (see dissertation System Integration / Positional Synchronisation
// section). Maps a desired physical angle to the digital command that
// actually achieves it, correcting for firmware gain mismatch and
// non-linear mechanical response. Negative torsion and negative
// horizontal are not covered here: negative torsion beyond ~-12 deg is a
// servo torque ceiling (not a calibration problem, so not correctable by
// a table), and negative horizontal is passed through uncompensated
// below pending further work.
const CalPoint torsionCal[] = {
  {0.0, 0.0}, {4.45, 5.0}, {6.84, 10.0}, {11.38, 14.0}, {13.23, 17.0}, {16.61, 19.0}
};
const int torsionCalN = sizeof(torsionCal) / sizeof(CalPoint);

const CalPoint verticalCal[] = {
  {0.0, 0.0}, {7.53, 3.0}, {14.91, 6.0}, {24.48, 9.0}, {34.02, 12.0}, {42.89, 15.0}, {54.97, 18.0}
};
const int verticalCalN = sizeof(verticalCal) / sizeof(CalPoint);

const CalPoint horizPosCal[] = {
  {0.0, 0.0}, {0.88, 1.0}, {2.64, 2.0}, {4.41, 3.0}, {5.29, 4.0}, {5.29, 5.0}, {7.95, 6.0}
};
const int horizPosCalN = sizeof(horizPosCal) / sizeof(CalPoint);

// Piecewise-linear interpolation over a calibration table.
float compensate(const CalPoint* table, int n, float desiredPhysical) {
  if (desiredPhysical <= table[0].physical) return table[0].digital;
  if (desiredPhysical >= table[n - 1].physical) return table[n - 1].digital;
  for (int i = 0; i < n - 1; i++) {
    if (desiredPhysical >= table[i].physical && desiredPhysical <= table[i + 1].physical) {
      float span = table[i + 1].physical - table[i].physical;
      if (span < 0.001) return table[i].digital; // guards duplicate points, e.g. h4/h5
      float frac = (desiredPhysical - table[i].physical) / span;
      return table[i].digital + frac * (table[i + 1].digital - table[i].digital);
    }
  }
  return table[n - 1].digital;
}

// --- Motor utilities ---
uint16_t angleToPulse(float angle) {
    angle = constrain(angle, SERVO_MIN, SERVO_MAX);
    return (uint16_t)(PULSE_MIN + (angle / 180.0) * (PULSE_MAX - PULSE_MIN));
}

float eyeToServo(float eyeAngle, float gainPos, float gainNeg, float trim) {
    float gain = (eyeAngle >= 0.0f) ? gainPos : gainNeg;
    return constrain(SERVO_NEUTRAL + trim + (eyeAngle * gain), (float)SERVO_MIN, (float)SERVO_MAX);
}

// Per-motor trim, currently all zero. Kept as named constants (rather
// than removed) so a future bench-calibration pass has somewhere
// obvious to put a correction without touching writeAllMotors().
#define TRIM_R_TORSION 0.0f
#define TRIM_L_TORSION 0.0f
#define TRIM_R_VERTICAL 0.0f
#define TRIM_L_VERTICAL 0.0f
#define TRIM_R_HORIZONTAL 0.0f
#define TRIM_L_HORIZONTAL 0.0f

#define GAIN_TORSION_POS      4.0f
#define GAIN_TORSION_NEG      4.0f   // start here, tune by bench test
#define GAIN_HORIZONTAL_POS   3.0f
#define GAIN_HORIZONTAL_NEG   2.0f   // start here, tune by bench test

// **********************************************
// writeAllMotors
//
//   Vertical:   same sign (both eyes go up)
//   Horizontal: opposite sign (both eyes move toward nose = convergent)
//   Torsion:    opposite sign (both tops tilt same direction in space)
//
// Right BPPV: right eye = primary
// Left BPPV:  left eye = primary
//
// eyeTorsion/eyeVertical/eyeHorizontal are run through the calibration
// tables above before being converted to servo angles, so every other
// part of the code (state machine, clamping, broadcastState) keeps
// working in real physical/clinical degrees, unchanged.
// **********************************************
void writeAllMotors() {
    float tCmd = eyeTorsion >= 0 ?  compensate(torsionCal, torsionCalN,  eyeTorsion)
                                  : -compensate(torsionCal, torsionCalN, -eyeTorsion);
    float vCmd = eyeVertical >= 0 ? compensate(verticalCal, verticalCalN,  eyeVertical)
                                  : -compensate(verticalCal, verticalCalN, -eyeVertical);
    float hCmd = eyeHorizontal >= 0 ? compensate(horizPosCal, horizPosCalN, eyeHorizontal)
                                     : eyeHorizontal; // negative side not yet calibrated

    pca.setPWM(R_CH_TORSION, 0, angleToPulse(eyeToServo(-tCmd, GAIN_TORSION_POS, GAIN_TORSION_NEG, TRIM_R_TORSION)));
    pca.setPWM(R_CH_VERTICAL, 0, angleToPulse(eyeToServo(vCmd, GAIN_VERTICAL, GAIN_VERTICAL, TRIM_R_VERTICAL)));
    pca.setPWM(R_CH_HORIZONTAL, 0, angleToPulse(eyeToServo(-hCmd, GAIN_HORIZONTAL_POS, GAIN_HORIZONTAL_NEG, TRIM_R_HORIZONTAL)));

    pca.setPWM(L_CH_TORSION, 0, angleToPulse(eyeToServo( tCmd, GAIN_TORSION_POS, GAIN_TORSION_NEG, TRIM_L_TORSION)));
    pca.setPWM(L_CH_VERTICAL, 0, angleToPulse(eyeToServo( vCmd, GAIN_VERTICAL, GAIN_VERTICAL, TRIM_L_VERTICAL)));
    pca.setPWM(L_CH_HORIZONTAL, 0, angleToPulse(eyeToServo( hCmd, GAIN_HORIZONTAL_POS, GAIN_HORIZONTAL_NEG, TRIM_L_HORIZONTAL)));
}

void allNeutral() {
    pca.setPWM(R_CH_HORIZONTAL, 0, PULSE_NEUTRAL);
    pca.setPWM(R_CH_VERTICAL, 0, PULSE_NEUTRAL);
    pca.setPWM(R_CH_TORSION, 0, PULSE_NEUTRAL);
    pca.setPWM(L_CH_HORIZONTAL, 0, PULSE_NEUTRAL);
    pca.setPWM(L_CH_VERTICAL, 0, PULSE_NEUTRAL);
    pca.setPWM(L_CH_TORSION, 0, PULSE_NEUTRAL);
    eyeTorsion = 0.0;
    eyeVertical = 0.0;
    eyeHorizontal = 0.0;
    beatState = BEAT_DRIFT;
    currentPhase = 0;
    motorRunning = false;
    testModeActive = false; // any neutral/reset also leaves test-hold mode
    Serial.print(F("PHASE:0,")); Serial.println(millis());
}

// Constrains commanded angles to the clinical peak limits, and prints a
// CLAMPED line whenever a requested angle actually gets capped, so an
// out-of-range request is never silent.
void clampEyeAngles() {
    float reqT = eyeTorsion, reqV = eyeVertical, reqH = eyeHorizontal;
    eyeTorsion = constrain(eyeTorsion, -PEAK_TORSION_DEG, PEAK_TORSION_DEG);
    eyeVertical = constrain(eyeVertical, -PEAK_VERTICAL_DEG, PEAK_VERTICAL_DEG);
    eyeHorizontal = constrain(eyeHorizontal, -PEAK_HORIZONTAL_DEG, PEAK_HORIZONTAL_DEG);
    if (reqT != eyeTorsion) {
        Serial.print(F("CLAMPED torsion requested ")); Serial.print(reqT, 2);
        Serial.print(F(" applied ")); Serial.println(eyeTorsion, 2);
    }
    if (reqV != eyeVertical) {
        Serial.print(F("CLAMPED vertical requested ")); Serial.print(reqV, 2);
        Serial.print(F(" applied ")); Serial.println(eyeVertical, 2);
    }
    if (reqH != eyeHorizontal) {
        Serial.print(F("CLAMPED horizontal requested ")); Serial.print(reqH, 2);
        Serial.print(F(" applied ")); Serial.println(eyeHorizontal, 2);
    }
}

void advancePhase(unsigned long now) {
    currentPhase++;
    phaseStartTime = now;
    lastMotorStep = now;
    beatState = BEAT_DRIFT;
    Serial.print(F("PHASE:")); Serial.print(currentPhase);
    Serial.print(F(",")); Serial.println(now);
}

// **********************************************
// startBPPV
// Sets which eye is primary
// motorDir controls torsion and horizontal direction in state machine
// **********************************************
void startBPPV(char side) {
    allNeutral();
    activeEye = side;
    motorDir = (side == 'R') ? 1 : -1;
    motorRunning = true;
    currentPhase = 1;
    phaseStartTime = millis();
    lastMotorStep = millis();
    beatState = BEAT_DRIFT;
    Serial.print(F("PHASE:1,")); Serial.println(phaseStartTime);
    Serial.print(F("BPPV started - side: ")); Serial.println(side);
    Serial.print(F("Primary eye: ")); Serial.println(side);
}

// **********************************************
// BPPV state machine
// motorDir applied to torsion and horizontal only
// Vertical always upbeat regardless of side
//
// Phase 1: latency drift, Phase 2: crescendo, Phase 3: nystagmus beating
// (the scored diagnostic pattern), Phase 4: decrescendo, Phase 5: reversal
// (drives back the opposite way after the scored interval ends).
// **********************************************
void runMotorStep() {
    unsigned long now = millis();
    float phaseT = (now - phaseStartTime) / 1000.0;
    float dt = constrain((now - lastMotorStep) / 1000.0, 0.0, 0.05);
    lastMotorStep = now;

    switch (currentPhase) {

        case 1: {
            float target = LATENCY_DRIFT_DEG * (phaseT / (LATENCY_MS / 1000.0));
            eyeTorsion = -motorDir * target * 0.8;
            eyeVertical = target * 0.6;
            eyeHorizontal = 0.0;
            if (phaseT >= LATENCY_MS / 1000.0) advancePhase(now);
            break;
        }

        case 2: {
            float frac = constrain(phaseT / (CRESCENDO_MS / 1000.0), 0.0, 1.0);
            float targetTorsion = -motorDir * CRESCENDO_TARGET_TORSION * frac;
            float targetVertical = CRESCENDO_TARGET_VERTICAL * frac;
            float targetHoriz = -motorDir * PEAK_HORIZONTAL_DEG * frac * 0.4;
            float maxStep = 15.0 * dt;
            eyeTorsion += constrain(targetTorsion - eyeTorsion, -maxStep, maxStep);
            eyeVertical += constrain(targetVertical - eyeVertical, -maxStep, maxStep);
            eyeHorizontal += constrain(targetHoriz - eyeHorizontal, -maxStep, maxStep);
            clampEyeAngles();
            if (phaseT >= CRESCENDO_MS / 1000.0) advancePhase(now);
            break;
        }

        case 3: {
            float envelope = exp(-phaseT / TAU_DECAY);
            float driftTarget = BEAT_DRIFT_DEG * envelope;

            if (beatState == BEAT_DRIFT) {
                eyeTorsion += motorDir * BEAT_DRIFT_SPEED_TOR * dt;
                eyeVertical -= BEAT_DRIFT_SPEED_VER * dt;
                eyeHorizontal += motorDir * BEAT_DRIFT_SPEED_HOR * dt;

                if (abs(eyeTorsion) >= driftTarget || abs(eyeVertical) >= driftTarget * 0.9) {
                    beatState = BEAT_SNAP;
                    Serial.print(F("DRIFT_END:")); Serial.print(now);
                    Serial.print(F(",")); Serial.println(eyeTorsion, 3);
                }
            }
            else {
                float snapStep = BEAT_SNAP_SPEED * dt;
                if (eyeTorsion > 0.0) eyeTorsion = max(0.0f, eyeTorsion - snapStep);
                else if (eyeTorsion < 0.0) eyeTorsion = min(0.0f, eyeTorsion + snapStep);

                if (eyeVertical > 0.0) eyeVertical = max(0.0f, eyeVertical - snapStep);
                else if (eyeVertical < 0.0) eyeVertical = min(0.0f, eyeVertical + snapStep);

                eyeHorizontal *= 0.85;

                if (fabs(eyeTorsion) <= 0.01 && fabs(eyeVertical) <= 0.01) {
                    eyeHorizontal = 0.0;
                    beatState = BEAT_DRIFT;
                    Serial.print(F("DRIFT_START:")); Serial.print(now);
                    Serial.print(F(",")); Serial.println(eyeTorsion, 3);
                }
            }
            clampEyeAngles();
            if (phaseT >= NYSTAGMUS_MS / 1000.0) advancePhase(now);
            break;
        }

        case 4: {
            float fade = constrain(1.0 - phaseT / (DECRESCENDO_MS / 1000.0), 0.0, 1.0);
            float driftTarget = BEAT_DRIFT_DEG * fade * 0.5;

            if (beatState == BEAT_DRIFT) {
                eyeTorsion -= motorDir * BEAT_DRIFT_SPEED_TOR * fade * dt;
                eyeVertical += BEAT_DRIFT_SPEED_VER * fade * dt;
                eyeHorizontal -= motorDir * BEAT_DRIFT_SPEED_HOR * fade * dt;
                if (abs(eyeTorsion) >= driftTarget || fade < 0.05) beatState = BEAT_SNAP;
            }
            else {
                float snapStep = BEAT_SNAP_SPEED * fade * dt;
                if (abs(eyeTorsion) > 0.3) {
                    eyeTorsion += eyeTorsion > 0 ? -snapStep : snapStep;
                } else {
                    eyeTorsion = 0.0;
                }
                if (abs(eyeVertical) > 0.3) {
                    eyeVertical += eyeVertical > 0 ? -snapStep : snapStep;
                } else {
                    eyeVertical = 0.0;
                }
                eyeHorizontal *= 0.9;
                if (abs(eyeTorsion) <= 0.3 && abs(eyeVertical) <= 0.3) {
                    eyeTorsion = 0.0; eyeVertical = 0.0; beatState = BEAT_DRIFT;
                }
            }
            clampEyeAngles();
            if (phaseT >= DECRESCENDO_MS / 1000.0) advancePhase(now);
            break;
        }

        case 5: {
            float fade = exp(-phaseT / 3.0);
            eyeTorsion -= motorDir * 9.4 * fade * dt;
            eyeVertical += 11.3 * fade * dt;
            eyeHorizontal += motorDir * 6.3 * fade * dt;
            eyeHorizontal = constrain(eyeHorizontal, -6.0, 6.0);
            clampEyeAngles();
            if (phaseT >= REVERSAL_MS / 1000.0) allNeutral();
            break;
        }
    }

    writeAllMotors();
}
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
void loop() {
    checkSerialCommands();

    // Drain FIFO silently when no serial activity.
    // Prevents 20-30 min overflow without touching DMP state.
    if (!SKIP_IMU_TEST) {
        uint16_t count = mpu.getFIFOCount();
        if (count >= 1024) {
            mpu.resetFIFO();
            return;
        }
        readIMU();
        if (jitterTrialActive) jitterTrialSample();
    }

    // While holding a fixed test angle (SECTION 2), skip the exam state
    // machine entirely and just keep driving the motors at the held values.
    if (testModeActive) {
        writeAllMotors();
    } else if (motorRunning) {
        runMotorStep();
    }

    static unsigned long lastBroadcast = 0;
    unsigned long now = millis();
    if (now - lastBroadcast >= LOOP_INTERVAL_MS) {
        broadcastState();
        lastBroadcast = now;
    }
}

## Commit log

2026-06-21 Working Simulation of Right Eye
    [iris.obj, sclera.obj]
2026-07-01 IMU Fixes and included rapid supine movement
2026-08-11 Included all the 3D models Used
    [Backdoor.stl, Ball Joint.stl, Body Of Robotic Bppv Head.stl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]
2026-08-15 Temporary included buildFiles
    [transfer_latency_results.csv]
2026-08-15 Updated buildFiles
    [transfer_latency_results.csv]
2026-08-20 Updated Folder Naming conventions
    [Backdoor.stl, Ball Joint.stl, Body Of Robotic Bppv Head.stl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]

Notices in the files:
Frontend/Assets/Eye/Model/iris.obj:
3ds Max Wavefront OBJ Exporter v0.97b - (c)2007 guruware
